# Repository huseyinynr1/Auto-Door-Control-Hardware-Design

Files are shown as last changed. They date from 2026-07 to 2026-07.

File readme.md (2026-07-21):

# Otomatik Tavuk Kümesi Kapısı Donanım Tasarımı

Bu sunum, **STM32F103C8T6 tabanlı otomatik tavuk kümesi kapısı kontrol sistemi** için hazırlanmış donanım tasarım dosyalarını içerir.

Sistem; Li-ion pil paketi ile beslenen ana kontrol kartı ve fırçalı DC motoru süren motor kontrol kartından oluşur. Ana kontrol kartı; kapı konumunu limit switch ile takip eder, IR sensör ile varlık algılar, pil gerilimini ADC üzerinden izler, TFT ekran, panel LED'leri ve panel butonları üzerinden kullanıcı arayüzünü yönetir. Motor kontrol kartı ise ana karttan gelen PWM/yön kontrol sinyalleriyle 12 V DC motoru sürer ve motor akım/gerilim geri bildirimlerini ana karta gönderir.

> Bu sunum ağırlıklı olarak PCB donanım tasarım dosyalarını içerir. Firmware/yazılım geliştirmesi buraya dahil değildir.

---

## Proje Özeti

Sistem ana beslemesini **Li-ion pil paketinden** alır. Ana kart üzerinde gerekli gerilim seviyelerini üretmek için güç dönüştürücü devreler bulunur. Motor sürüş işlemi ise ayrı tasarlanan **Automatic Door Motor Control Board** üzerinden gerçekleştirilir.

Sistemde bulunan temel donanımlar:

- **Li-ion pil paketi ana besleme girişi**
- **12 V → 5 V buck converter güç katı**
- **5 V → 3.3 V LDO regülatör güç katı**
- **STM32F103C8T6 mikrodenetleyici**
- **Harici 8 MHz HSE kristal**
- **Harici 32.768 kHz LSE kristal**
- **TFT ekran arayüzü**
- **Motor PWM ve yön kontrol çıkışları**
- **12 V DC worm gear motor sürüş katı**
- **Motor akım geri bildirimi**
- **Motor gerilim geri bildirimi**
- **Kullanıcı buton girişleri**
- **Panel durum LED çıkışları**
- **Düşük pil algılama devresi**
- **IR varlık/engel sensörü girişi**
- **Kapı tam açık / tam kapalı limit switch girişleri**
- **SWD programlama ve debug bağlantısı**
- **Ana besleme hatları için test point'ler**

Genel sistem bağlantısı:

```text
Main Board → PWM / Control Signals → Motor Control Board → DC Motor
                         ↑
              Motor Voltage / Current Feedback
```

---

## Donanım Blokları

### Güç Devresi

Kartın ana beslemesi Li-ion pil paketidir. Giriş gerilimi önce buck converter ile 5 V seviyesine düşürülür. Ardından 5 V hattından LDO regülatör ile 3.3 V lojik besleme hattı üretilir.

| Hat | Kaynak | Kullanım Amacı |
|---|---|---|
| Pil Girişi | Li-ion pil paketi | Ana sistem beslemesi |
| 5 V | Buck converter | Sensör/periferik beslemesi |
| 3.3 V | LDO regülatör | MCU ve lojik devre beslemesi |

Güç bölümünde giriş filtreleme, koruma elemanları, regüle çıkış devreleri ve pil gerilimi ölçüm katı bulunmaktadır.

Pil gerilimi, **50 kΩ / 10 kΩ** gerilim bölücü ile yaklaşık **1/6 oranında** küçültülür. Böylece nominal **12.6 V** pil gerilimi ADC ölçüm hattında yaklaşık **2.1 V**, ölçüm üst sınırı olarak değerlendirilen **18 V** ise yaklaşık **3.0 V** seviyesine dönüştürülür.

Gerilim bölücü çıkışı, **1 kΩ + 47 nF** alçak geçiren filtreden geçirilir ve **MCP6001** op-amp gerilim takipçisi ile tamponlanır. Op-amp, yüksek empedanslı gerilim bölücü düğümünü MCU ADC girişinden ayırarak `BATTERY_VOLTAGE` hattına düşük empedanslı ve daha kararlı bir ölçüm sinyali verir. Op-amp çıkışındaki **10 Ω** seri direnç, ADC hattındaki küçük kapasitif yükten op-amp çıkışını ayırır.

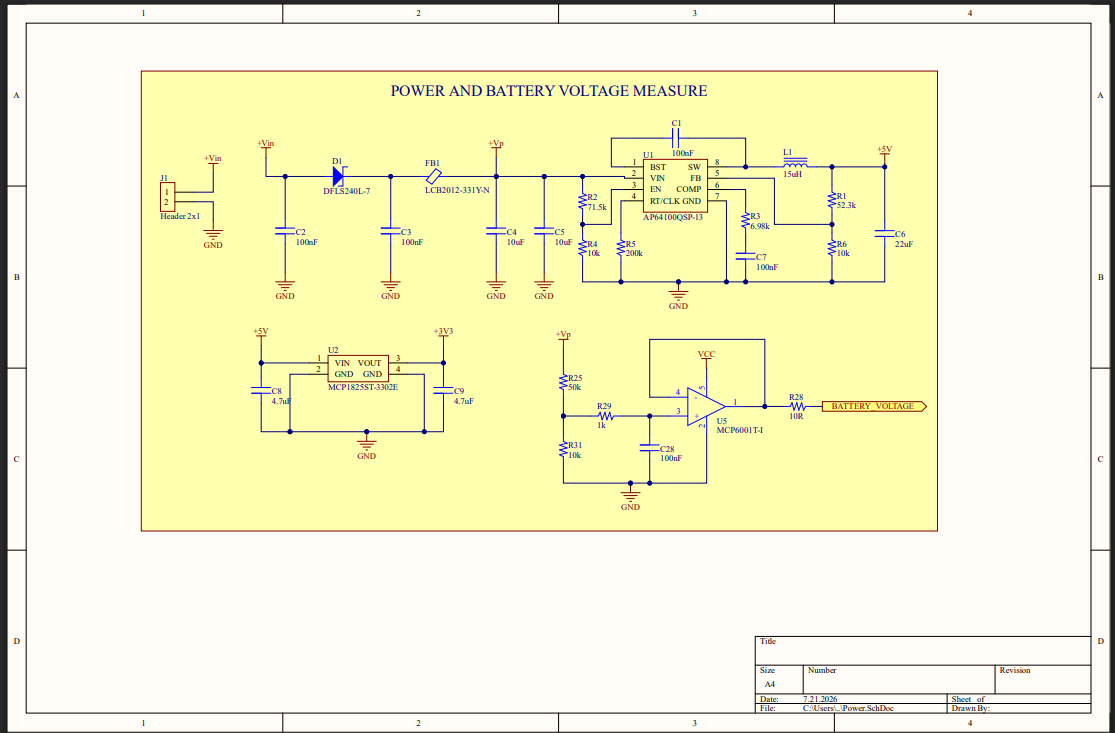
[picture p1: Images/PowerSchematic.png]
Power Schematic


---

### Mikrodenetleyici Bölümü

Ana kontrolcü olarak **STM32F103C8T6** kullanılmıştır.

MCU bölümünde bulunan temel yapılar:

- STM32F103C8T6 mikrodenetleyici
- Harici 8 MHz HSE kristal
- Harici 32.768 kHz LSE kristal
- MCU besleme dekuplaj kapasitörleri
- Reset / boot bağlantıları
- SWD programlama ve debug header'ı
- 3.3 V lojik besleme bağlantıları
- Pil gerilimi için `BATTERY_VOLTAGE` ADC girişi
- Motor akımı için `MOTOR_CURRENT` ADC girişi
- Motor uç gerilimleri için `MOTOR_VSENSE_A` ve `MOTOR_VSENSE_B` ADC girişleri

Motor kontrol kartından gelen op-amp tamponlu analog sinyaller, ana kart üzerinde MCU ADC kanallarına bağlanır. Her ADC girişinde, örnekleme anındaki kısa süreli akım ihtiyacını karşılamak ve yüksek frekanslı parazitleri azaltmak için MCU pinine yakın **4.7 nF** kondansatör kullanılır. Aynı yöntem `BATTERY_VOLTAGE` ölçüm girişinde de uygulanır.

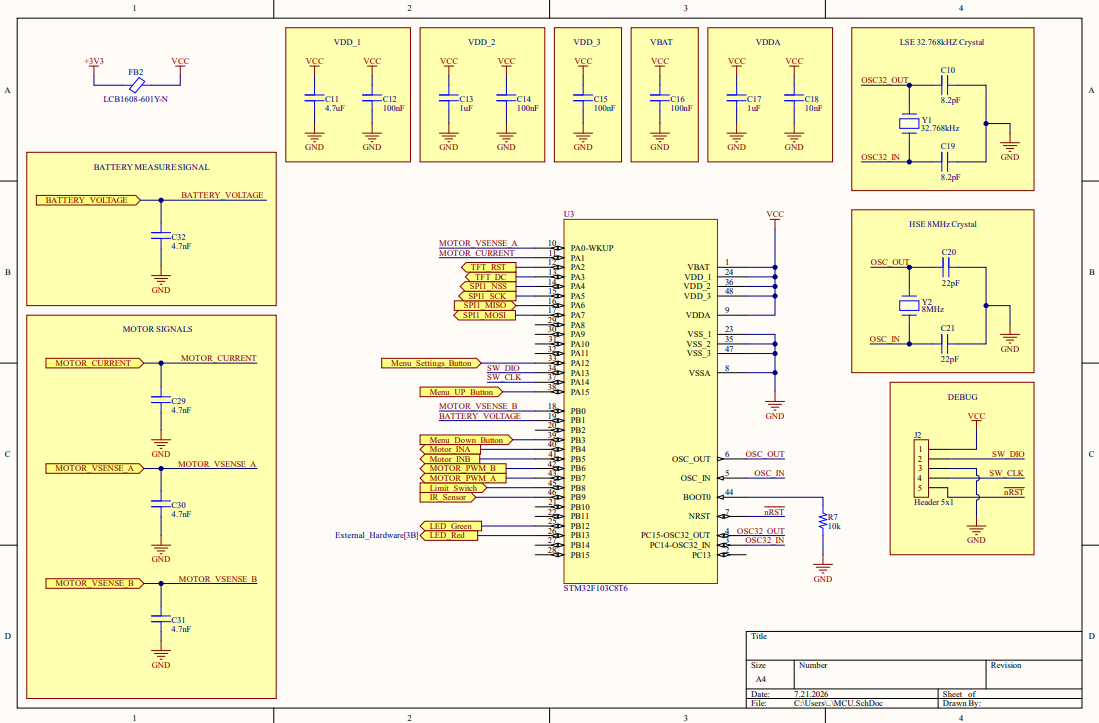
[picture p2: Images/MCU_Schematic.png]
MCU Schematic


---

### Harici Donanım Arayüzleri

Ana kontrol kartı, otomatik kapı sisteminde kullanılan harici donanımlar için gerekli bağlantı ve kontrol arayüzlerini içerir.

Desteklenen harici bağlantılar:

- TFT ekran bağlantısı
- Motor kontrol kartına PWM ve yön sinyalleri
- Motor akım/gerilim geri bildirim girişleri
- Kullanıcı buton girişleri
- Panel durum LED çıkışları
- IR varlık/engel sensörü girişi
- Kapı tam açık/tam kapalı limit switch girişi

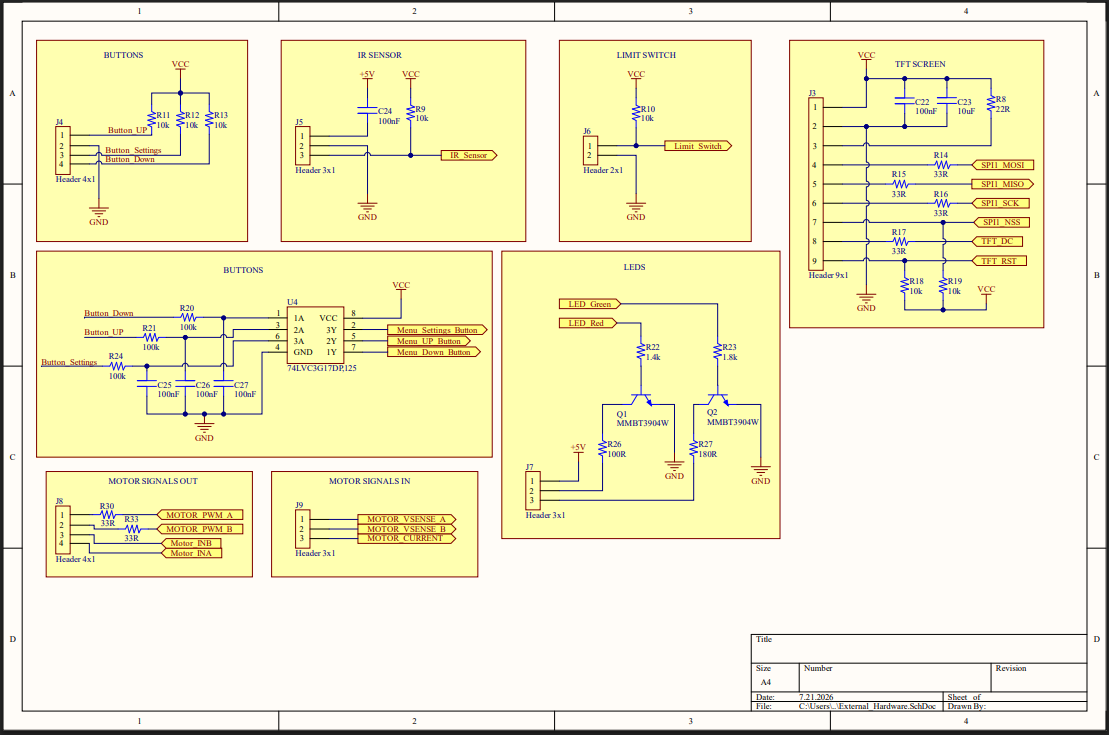
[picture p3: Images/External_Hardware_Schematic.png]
External Hardware Schematic


---

### Motor Control Board 

Motor Control Board, 12 V fırçalı DC motorun çift yönlü ve PWM kontrollü sürülmesi için ana kontrol kartından ayrı bir güç kartı olarak tasarlanmıştır. Kart yaklaşık **60 mm x 53 mm** boyutundadır ve dört adet montaj deliğine sahiptir.

Kartın temel bölümleri:

- Girişte resetlenebilir PTC sigorta, seri Schottky diyot ve SMBJ15CA TVS koruması
- 330 uF bulk kapasitör ile giriş filtreleme
- İki adet IR2103 yarım-köprü gate driver
- İki adet PJL9850 çift N-kanal MOSFET ile oluşturulan tam H-köprü
- Motorun çift yönlü sürülmesi ve PWM ile hız kontrolü
- 5 mOhm şönt direnç ve MCP6001 op-amp ile motor akım ölçümü
- Motorun iki terminali için gerilim bölücü, RC filtre ve MCP6001 buffer devreleri
- Ölçüm devreleri için filtrelenmiş 3.3 V analog besleme
- Ana kontrol kartına üç analog geri bildirim çıkışı

#### Motor Kontrol Sinyalleri

| Sinyal | Açıklama |
| --- | --- |
| `Motor_PWM_A` | A yarım-köprüsü PWM kontrolü |
| `Motor_PWM_B` | B yarım-köprüsü PWM kontrolü |
| `Motor_INA` | A yarım-köprüsü yön/alt anahtar kontrolü |
| `Motor_INB` | B yarım-köprüsü yön/alt anahtar kontrolü |

#### Ölçüm ve Geri Bildirim Sinyalleri

| Sinyal | Açıklama |
| --- | --- |
| `MOTOR_CURRENT` | Şönt direnç üzerinden yükseltilmiş motor akım ölçümü |
| `MOTOR_VREF_A` | Motorun A terminaline ait ölçeklendirilmiş gerilim |
| `MOTOR_VREF_B` | Motorun B terminaline ait ölçeklendirilmiş gerilim |

Bu geri bildirimler, yazılım tarafında motor akımının izlenmesi, sıkışma/stall durumunun belirlenmesi ve motor uç gerilimlerinden hareket bilgisinin değerlendirilmesi için kullanılacaktır.

#### Motor Güç ve Sürücü Şematiği

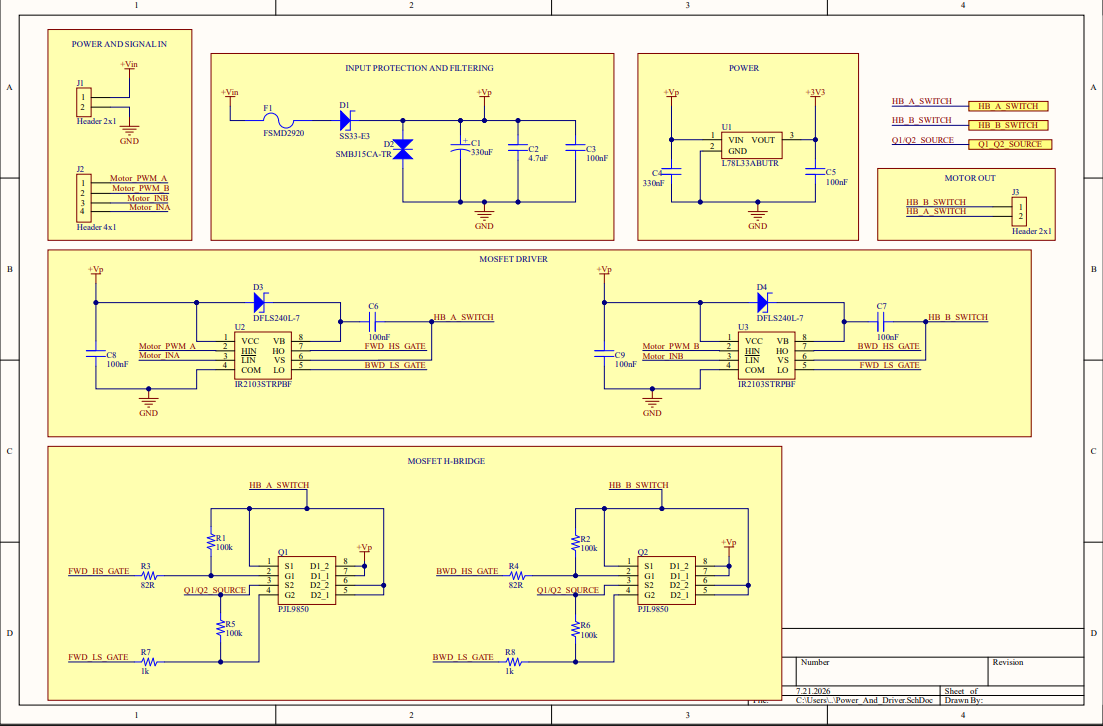
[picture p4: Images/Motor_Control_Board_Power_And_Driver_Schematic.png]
Motor Control Board V2 Power and Driver Schematic


#### Motor Ölçüm Şematiği

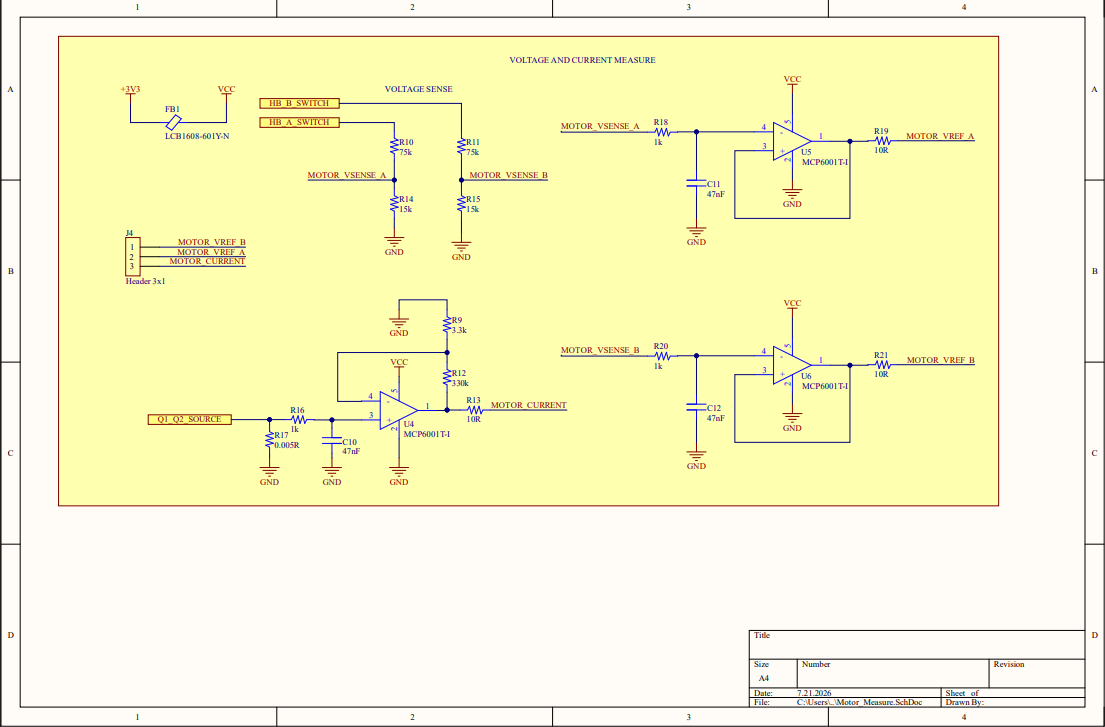
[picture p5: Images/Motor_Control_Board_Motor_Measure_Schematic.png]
Motor Control Board V2 Motor Measure Schematic


---

### Motor Driver Topology

Motor sürüş katı, **4 adet N-channel MOSFET** ile oluşturulmuş high-side / low-side **H-bridge** yapısına sahiptir. MOSFET'ler iki adet half-bridge MOSFET driver ile sürülür.

Kullanılan temel sürüş mantığı:

| Çalışma Durumu | PWM_A | IN_A | PWM_B | IN_B |
|---|---|---|---|---|
| Forward | Active | Active | Passive | Passive |
| Reverse | Passive | Passive | Active | Active |
| Stop | Passive | Passive | Passive | Passive |

Bu yapı sayesinde motor yön kontrolü ve PWM tabanlı hız/enerji kontrolü ana kart üzerinden gerçekleştirilebilir.

### Input Protection and Filtering

Motor kontrol kartının giriş bölümünde güç hattını korumak ve filtrelemek için aşağıdaki yapılar bulunur:

- PTC resettable fuse
- Reverse polarity protection Schottky diode
- TVS diode
- Bulk input capacitor
- MLCC input filter capacitors

Bu bölüm, motor kartının giriş beslemesini ters bağlantı, ani gerilim darbeleri ve besleme hattı gürültülerine karşı daha dayanıklı hale getirmek için tasarlanmıştır.

### Motor Current Sensing

Motor akımı low-side shunt direnç üzerinden ölçülür. Shunt üzerinde oluşan düşük seviyeli voltaj, op-amp tabanlı sinyal koşullandırma devresiyle ana karta uygun ölçüm sinyali haline getirilir.

Bu geri bildirim aşağıdaki amaçlarla kullanılabilir:

- Motor yük durumunun izlenmesi
- Sıkışma / stall durumunun algılanması
- Aşırı akım durumlarının yazılımsal olarak takip edilmesi
- Motor hareketinin güvenlik açısından denetlenmesi

### Motor Voltage Sensing

Motorun her iki terminali (`HB_A_SWITCH` ve `HB_B_SWITCH`) ayrı ayrı ölçülmektedir. Terminal gerilimleri, 75 kΩ / 15 kΩ gerilim bölücüler ile yaklaşık **1/6 oranında düşürülerek** `MOTOR_VSENSE_A` ve `MOTOR_VSENSE_B` sinyallerine dönüştürülür.

Bu sinyaller, 1 kΩ direnç ve 47 nF kondansatörden oluşan giriş filtresinden geçirildikten sonra MCP6001 op-amp'ları tarafından gerilim takipçisi (unity-gain buffer) olarak tamponlanır. Böylece gerilim bölücü devresi ADC girişinden izole edilir ve ana karta daha kararlı, düşük empedanslı ölçüm sinyalleri iletilir.

Motor gerilim geri bildirim sinyalleri:

- `MOTOR_VREF_A`
- `MOTOR_VREF_B`

Ana kart, bu iki geri bildirim sinyali arasındaki farkı kullanarak motor uçları arasındaki gerçek gerilimi hesaplayabilir.

Motor akım geri bildirim sinyali:

- `MOTOR_CURRENT`

### Main Board Interface

Motor kontrol kartı ana karta aşağıdaki sinyaller üzerinden bağlanır:

| Sinyal | Yön | Açıklama |
|---|---|---|
| `Motor_PWM_A` | Main Board → Motor Control Board | A yönü PWM kontrol sinyali |
| `Motor_INA` | Main Board → Motor Control Board | A yönü enable/direction kontrol sinyali |
| `Motor_PWM_B` | Main Board → Motor Control Board | B yönü PWM kontrol sinyali |
| `Motor_INB` | Main Board → Motor Control Board | B yönü enable/direction kontrol sinyali |
| `MOTOR_VREF_A` | Motor Control Board → Main Board | Motor A terminali gerilim geri bildirimi |
| `MOTOR_VREF_B` | Motor Control Board → Main Board | Motor B terminali gerilim geri bildirimi |
| `MOTOR_CURRENT` | Motor Control Board → Main Board | Motor akım geri bildirimi |

### PCB Design

Motor kontrol kartı **2-layer PCB** olarak tasarlanmıştır. Kart üzerinde motor akımı taşıyan güç yolları geniş tutulmuş, GND dönüş yolu için polygon pour yapısı kullanılmıştır. Motor akımı, motor gerilimi ve sürücü kontrol sinyalleri ayrı izleme/geri bildirim hatları olarak ana karta taşınır.

---

## PCB Görünümleri

### Main Board - PCB Üst Görünüm

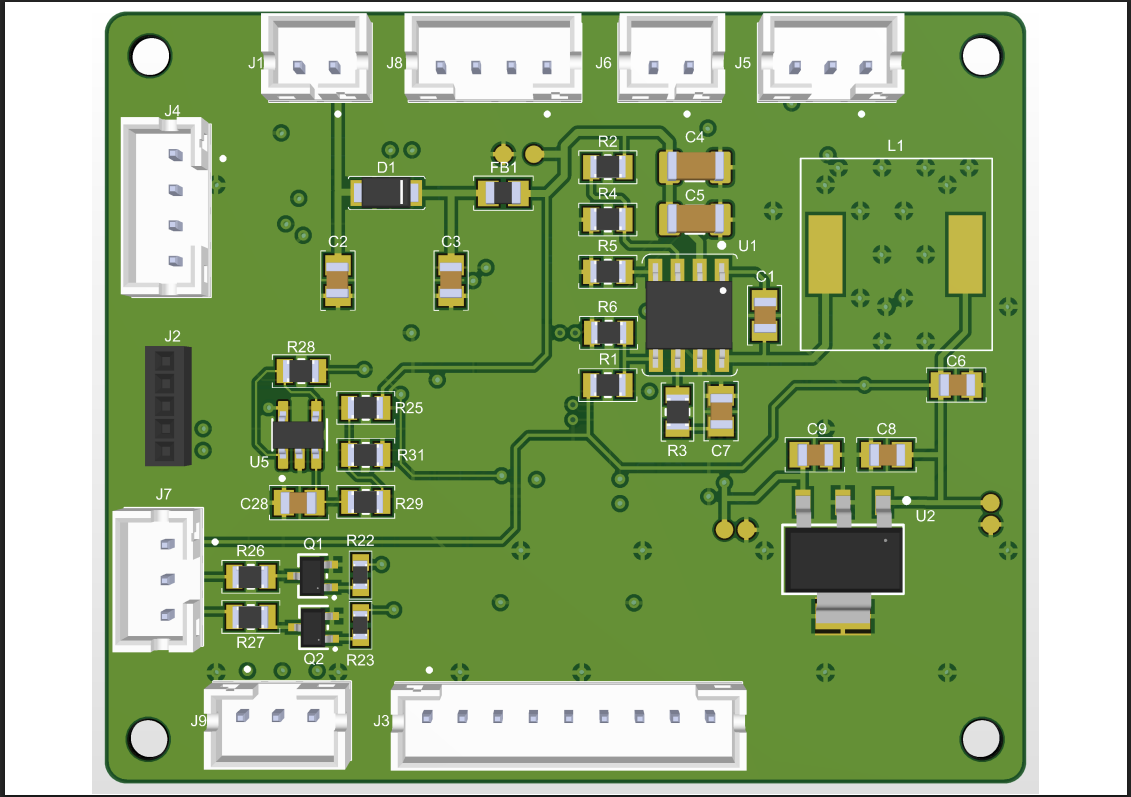
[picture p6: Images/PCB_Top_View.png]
Main Board PCB Top View


### Main Board - PCB Alt Görünüm

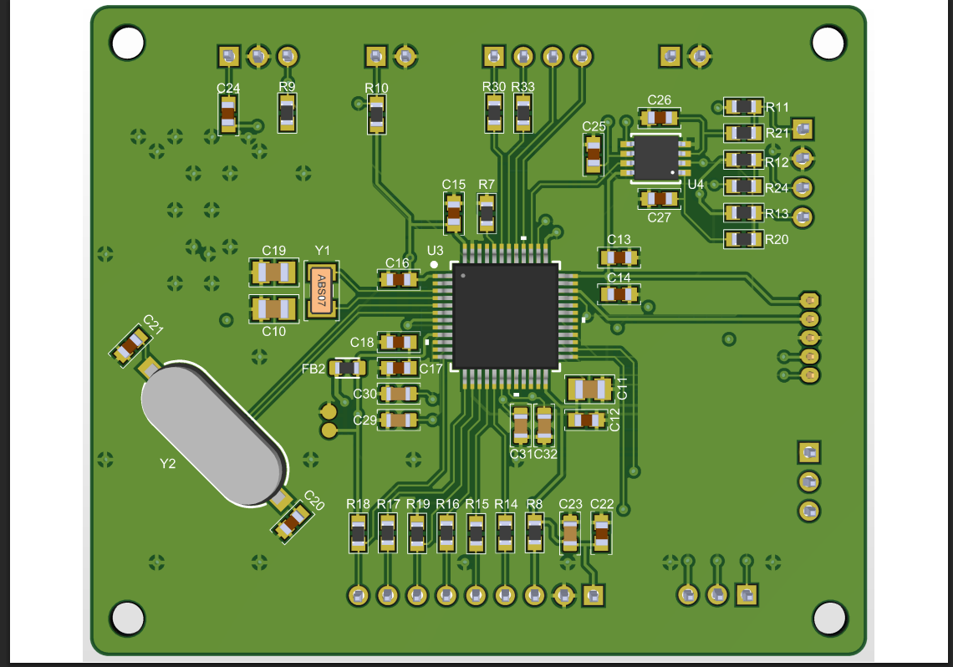
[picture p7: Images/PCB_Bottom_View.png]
Main Board PCB Bottom View


### Motor Control Board - PCB Üst Görünüm

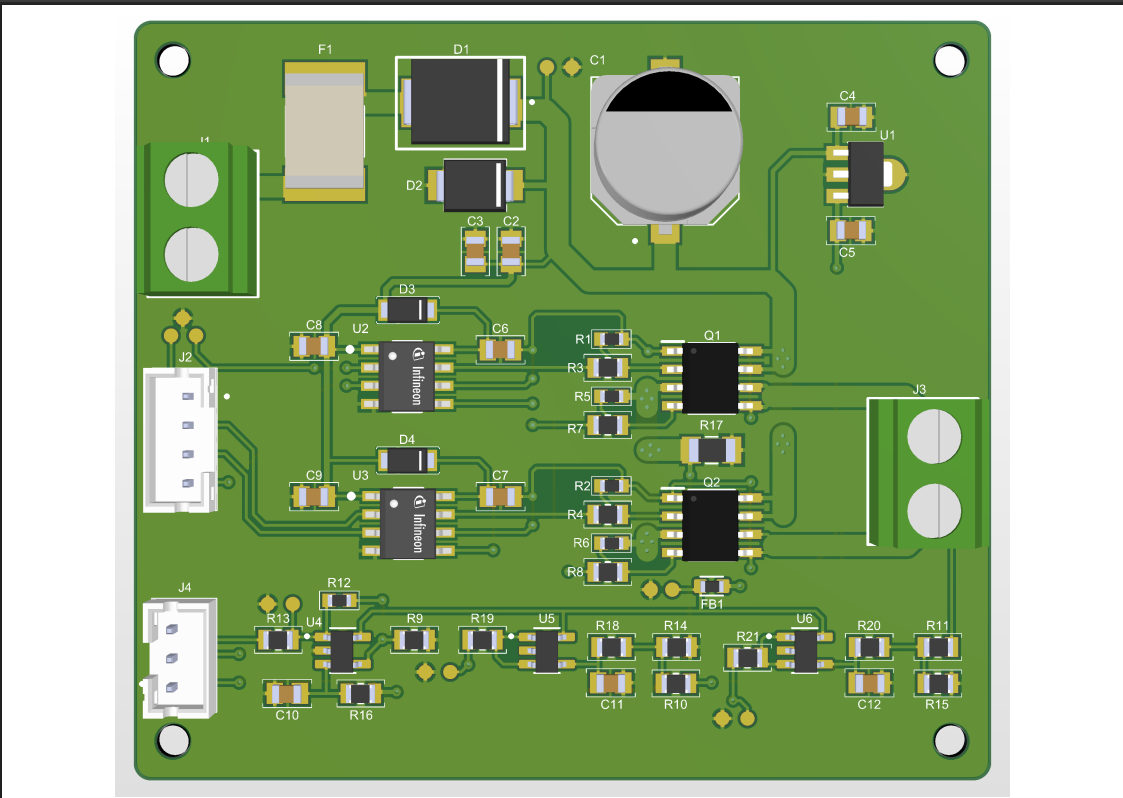
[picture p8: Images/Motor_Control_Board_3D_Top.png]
Motor Control Board 3D Top View


---

## Dosya Yapısı

```text
.
├── Design_Files/
│   ├── Chicken_Coop_Door_Main_Board_V3.PcbDoc
│   ├── Chicken_Coop_Door_Main_Board_V3.PrjPcb
│   ├── Chicken_Coop_Door_Main_Board_V3.PrjPcbStructure
│   ├── Power.SchDoc
│   ├── MCU.SchDoc
│   ├── External_Hardware.SchDoc
│   ├── Chicken_Coop_Door_Motor_Control_Board_V2.PrjPcb
│   ├── Chicken_Coop_Door_Motor_Control_Board_V2.PrjPcbStructure
│   ├── Chicken_Coop_Door_Motor_Control_Board_V2.PcbDoc
│   └── Power_And_Driver.SchDoc
│   └── Motor_Measure.SchDoc
│
├── Images/
│   ├── Power.png
│   ├── MCU_Schematic.png
│   ├── External_Hardware_Schematic.png
│   ├── Motor_Control_Board_Power_And_Driver_Schematic.png
│   ├── Motor_Control_Board_Motor_Measure_Schematic.png
│   ├── PCB_Top_View.png
│   ├── PCB_Bottom_View.png
│   ├── Motor_Control_Board_3D_Top.png
│
├── Production/
│   ├── Bill of Materials-Chicken_Coop_Door_Main_Board_V3.xlsx
│   └── Bill of Materials-Chicken_Coop_Door_Motor_Control_Board_V2.xlsx
│
└── README.md
```

---

## Tasarım Dosyaları

PCB tasarımları **Altium Designer** kullanılarak hazırlanmıştır.

Sunumda bulunan temel Altium dosyaları:

| Dosya | Açıklama |
|---|---|
| `Chicken_Coop_Door_Main_Board_V3.PrjPcb` | Ana kontrol kartı Altium PCB proje dosyası |
| `Chicken_Coop_Door_Main_Board_V3.PcbDoc` | Ana kontrol kartı PCB layout dosyası |
| `Power.SchDoc` | Ana kontrol kartı güç devresi şematik dosyası |
| `MCU.SchDoc` | Mikrodenetleyici devresi şematik dosyası |
| `External_Hardware.SchDoc` | Harici donanım arayüzleri şematik dosyası |
| `Chicken_Coop_Door_Main_Board_V3.PrjPcbStructure` | Ana kontrol kartı Altium proje yapı dosyası |
| `Chicken_Coop_Door_Motor_Control_Board_V2.PrjPcb` | Motor kontrol kartı Altium PCB proje dosyası |
| `Chicken_Coop_Door_Motor_Control_Board_V2.PcbDoc` | Motor kontrol kartı PCB layout dosyası |
| `Power_And_Driver.SchDoc` | Motor kontrol kartı şematik dosyası |
| `Motor_Measure.SchDoc` | Motor kontrol kartı şematik dosyası |

---

## Malzeme Listesi

BOM dosyaları `Production` klasörü altında yer almaktadır:

```text
Production/Bill of Materials-Chicken_Coop_Door_Main_Board_V3.xlsx
Production/Bill of Materials-Chicken_Coop_Door_Motor_Control_Board_v2.xlsx
```

Bu dosyalar, projede kullanılan komponentleri, değerleri, üretici bilgilerini ve footprint bilgilerini içerir.

---

## Ana Fonksiyonel Bölümler

### 1. Pil Girişi ve Güç Regülasyonu

Kartın ana beslemesi, seri bağlı Li-ion hücrelerden oluşan pil paketi üzerinden sağlanacak şekilde tasarlanmıştır. Pil gerilimi buck converter devresi ile 5 V seviyesine düşürülür. Ardından 5 V hattından LDO regülatör ile 3.3 V lojik besleme hattı elde edilir.

Pil gerilimi ayrıca 50 kΩ / 10 kΩ bölücü, 1 kΩ + 47 nF alçak geçiren filtre ve MCP6001 buffer üzerinden `BATTERY_VOLTAGE` sinyaline dönüştürülerek MCU ADC kanalına iletilir. Böylece pil seviyesi ve düşük/aşırı gerilim durumları ayrı comparator devresi yerine yazılım tarafından izlenebilir.

### 2. MCU Kontrol Bölümü

STM32F103C8T6 mikrodenetleyici aşağıdaki işlemleri yönetmek için kullanılır:

- Kapı motor kontrol komutlarının üretilmesi
- Kullanıcı butonlarının okunması
- TFT ekran arayüzü
- Sensör ve limit switch girişlerinin okunması
- `BATTERY_VOLTAGE` ADC ölçümünden pil durumunun takip edilmesi
- Kırmızı ve yeşil panel LED çıkışlarının kontrol edilmesi
- `MOTOR_CURRENT`, `MOTOR_VSENSE_A` ve `MOTOR_VSENSE_B` ADC geri bildirimlerinin değerlendirilmesi

### 3. Motor Kontrol Arayüzü

Ana kontrol kartı motor güç katını doğrudan üzerinde taşımaz. Bunun yerine **Automatic Door Motor Control Board** kartına PWM ve yön kontrol sinyalleri gönderir. Motor kontrol kartı bu sinyallerle H-bridge güç katını sürer ve motoru ileri/geri yönde çalıştırır.

### 4. Motor Sürüş ve Geri Bildirim Bölümü

Motor kontrol kartı üzerinde 12 V DC motoru süren H-bridge güç katı, MOSFET driver devreleri, giriş koruma/filtreleme yapısı, motor akım ölçüm devresi ve motor gerilim ölçüm devreleri bulunur.

Bu yapı sayesinde motor sürüşü ana karttan fiziksel olarak ayrılır ve motorun elektriksel davranışı geri bildirim sinyalleri ile izlenebilir.

### 5. Kullanıcı Arayüzü

Kullanıcı arayüzü için ana kart üzerinde aşağıdaki bağlantılar yer alır:

- TFT ekran bağlantısı
- Kullanıcı butonları
- Panel durum LED çıkışları

Bu arayüzler, sistem durumunun görüntülenmesi ve kullanıcıdan manuel komut alınması için kullanılır.

### 6. Sensör ve Geri Bildirim Girişleri

Kart üzerinde kapı hareketini ve çevresel koşulları takip etmek için çeşitli girişler bulunur:

- IR varlık sensörü
- Kapı tam açık - kapalı limit switch'i
- Düşük pil algılama girişi
- Motor akım geri bildirimi
- Motor gerilim geri bildirimi

Bu sinyaller, kapı hareketinin güvenli ve kontrollü şekilde yönetilmesini sağlar.

---

## Yazar

**Hüseyin Yanar**

Elektrik-Elektronik Mühendisi

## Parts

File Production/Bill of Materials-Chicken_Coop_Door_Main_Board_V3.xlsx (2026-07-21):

Comment | Description | Designator | Footprint | LibRef | Quantity | Capacitance | Resistance | Manufacturer | Manufacturer Code | Manufacturer Product Number | Manufacturer_Part_Number | Manufacturer_Name
100nF | MLCC 0805 100nF 50VDC ±10% X7R, MLCC (2012) 0805 10nF 50VDC ±10% X7R | C1, C2, C3, C7, C28 | CAPC2012X145N 0805 | CAP 0805 100nF, CAP 0805 100nF CC0805JRX7R9BB104, CAP 0805 10nF CC0805KRX7R9BB103 | 5 | 100nF, 10nF |  | SAMSUNG, YAGEO | CL21B104KBCNNNC, CC0805JRX7R9BB104, CC0805KRX7R9BB103
10uF | MLCC (3216) 1206 10uF 50VDC ±10% X5R | C4, C5 | CAPC 1206 3216X180N | CAP 1206 10uF CL31A106KBHNNNE | 2 | 10 uF |  | Samsung Electro-Mechanics |  | CL31B225KCHSNNE
22uF | MLCC (2012) 0805 22uF 16VDC ±10% X5R CL21A226KOQNNNE | C6 | CAPC2012X145N 0805 | CAP 0805 22uF CL21A226KOQNNNE | 1 | 22 µF |  | SAMSUNG |  | CL21A226KOQNNNE
4.7uF | MLCC (2012) 0805 4.7uF 25VDC ±10% X5R, MLCC (2012) 0805 4.7uF 16VDC ±10% X7R AUTOMOTIVE | C8, C9, C11 | CAPC2012X145N 0805 | CAP 0805 4.7uF CL21A475KAQNNNE, CAP 0805 4.7uF CL21B475KOQVPNE | 3 | 4.7uF |  | SAMSUNG |  | CL21A475KAQNNNE, CL21B475KOQVPNE
8.2pF | MLCC (2012) 0805 8.2pF 50VDC ±0.5pF C0G (NP0) | C10, C19 | CAPC2012X145N 0805 | CAP 0805 8.2pF CC0805DRNPO9BN8R2 | 2 | 8.2pF |  | YAGEO | CC0805DRNPO9BN8R2
100nF | MLCC (1608) 0603 100nF 25VDC ±10% X7R | C12, C14, C15, C16, C22, C24, C25, C26, C27 | CAPC 0603 1608X90N | CAP 0603 100nF CC0603KPX7R8BB104 | 9 | 100nF |  | YAGEO |  | CC0603KPX7R8BB104
1uF | MLCC (1608) 0603 1uF 16VDC ±10% X5R | C13, C17 | CAPC 0603 1608X90N | CAP 0603 1uF C0603C105K4PACTU | 2 | 1uF |  | KEMET |  | C0603C105K4PACTU
10nF | MLCC (1608) 0603 10nF 25VDC ±10% X7R | C18 | CAPC 0603 1608X90N | CAP 0603 10nF CL10B103KA8NNNC | 1 | 10nF |  | SAMSUNG |  | CL10B103KA8NNNC
22pF | MLCC (1608) 0603 22pF 50VDC ±5% C0G (NP0) | C20, C21 | CAPC 0603 1608X90N | CAP 0603 22pF CC0603JRNPO9BN220 | 2 | 22pF |  | YAGEO |  | CC0603JRNPO9BN220
10uF | MLCC (1608) 0603 10uF 10VDC ±10% X5R | C23 | CAPC1608X90N 0603 | CAP 0603 10uF CL10A106KP8NNNC | 1 | 10uF |  | SAMSUNG | CL10A106KP8NNNC
4.7nF | MLCC (1608) 0603 4.7nF 50VDC ±10% X7R | C29, C30, C31, C32 | CAPC1608X90N 0603 | CAP 0603 4.7nF CL10B472KB8NNNC | 4 | 4.7nF |  | SAMSUNG | CL10B472KB8NNNC
DFLS240L-7 | DIODE SCHOTTK 40V 2A POWERDI 123 | D1 | DIODE DFLS240L-7 POWERDI 123 | DIODE SCHOTTKY DFLS240L-7 | 1 |  |  | Diodes Incorporated |  | DFLS240L-7
LCB2012-331Y-N | FERRITE BEAD 0805 330R/100MHZ SMD | FB1 | BEADC2012X105N MPZ2012S601ATD25 | Ferrite Bead LCB2012-331Y-N | 1 |  |  | CORE MASTER |  | LCB2012-331Y-N
LCB1608-601Y-N | 600 Ohms @ 100 MHz 1 Power Line Ferrite Bead 0603 (1608 Metric) 1A 200mOhm | FB2 | MPZ1608S601ATA00 0603 1608X95N | Ferrite Bead LCB1608-601Y-N | 1 |  |  | CORE MASTER | LCB1608-601Y-N
Header 2x1 | CON.T.B.2.00MM 2P 180C MALE CONNFLY | J1, J6 | JST_B2B-PH-K-S 1x2 Header | Header 2x1 DS1066-2MVW6X | 2 |  |  | CONNFLY |  | DS1066-2MVW6X
Header 5x1 | FEMALE HEADER 5PIN(1x5) 2.54mm THT V/T BAG | J2 | Header 5x1 FEMALE Header | Header 5x1 Female Header | 1 |  |  | KLS ELECTRONIC |  | L-KLS1-208-1-05-S
Header 9x1 | CON.T.B.2.00MM 9P 180C MALE WHITE CONNFLY | J3 | Header 9x1 JST_B9B-PH-K-S | Header 9x1 DS1066-9MVW6S | 1 |  |  | CONNFLY |  | DS1066-9MVW6S
Header 4x1 | CON.T.B.2MM 4P 180C MALE WHITE CONNFLY | J4, J8 | JST_B4B-PH-K-S 1x4 Header | Header 4x1 DS1066-4MVW6X | 2 |  |  | CONNFLY |  | DS1066-4MVW6X
Header 3x1 | CON.T.B.2.00MM 3P 180C MALE CONNFLY | J5, J7, J9 | JST_B3B-PH-K-S 1x3 Header | Header 3x1 DS1066-3MVW6X | 3 |  |  | CONNFLY |  | DS1066-3MVW6X
15uH | INDUCTOR POWER 15UH 10X10X4.5MM SMD | L1 | Inductor SRI1004-150M | 15uH Inductor SRI1004-150M | 1 |  |  | CORE MASTER |  | SRI1004-150M
MMBT3904W | Bipolar (BJT) Transistor NPN 40 V 200 mA 150 mW Surface Mount SOT-323 | Q1, Q2 | MMBT3904_PNJ | NPN Transistor MMBT3904W | 2 |  |  | Panjit International Inc. |  | MMBT3904W_R1_00001
52.3k | RES.(2012) 0805 52.3K Ohms 1% 1/8W-S 100PPM | R1 | RES 0805 YAGEO C2012X60N | RES 0805 52.3k 0805S8F5232T5E | 1 |  | 52.3k Ohms | ROYALOHM | 0805S8F5232T5E
71.5k | RES.(2012) 0805 71.5k Ohms 1% 1/8W-S 100PPM | R2 | RES 0805 YAGEO C2012X60N | RES 0805 71.5k Ohms 0805S8F7152T5E | 1 |  | 71.5k Ohms | ROYALOHM | 0805S8F7152T5E
6.98k | RES.(2012) 0805 6.98K Ohms 1% 1/10W 100PPM | R3 | RES 0805 YAGEO C2012X60N | RES 0805 6.98k 0805WAF6981T5E | 1 |  | 6.98k Ohms | ROYALOHM | 0805WAF6981T5E
10k | RES.(2012) 0805 10K Ohms 1% 1/8W-S 100PPM | R4, R6, R31 | RES 0805 YAGEO C2012X60N | RES 0805 10k 0805S8F1002T5E | 3 |  | 10k Ohms | ROYALOHM | 0805S8F1002T5E
200k | RES.(2012) 0805 200K Ohms 1% 1/8W-S 100PPM | R5 | RES 0805 YAGEO C2012X60N | RES 0805 200k 0805S8F2003T5E | 1 |  | 200k Ohms | ROYALOHM | 0805S8F2003T5E
10k | RES.(1608) 0603 10K Ohms 5% 1/10W-S 100PPM | R7, R9, R10, R11, R12, R13, R18, R19 | RES 0603 ROYALOHM | RES 0603 10k 0603SAJ0103T5E | 8 |  | 10 kOhms | ROYALOHM |  | 0603SAJ0103T5E
22R | RES.(1608) 0603 22 Ohms 5% 1/10W-S 200PPM | R8 | RES 0603 ROYALOHM | RES 0603 22 Ohms 0603SAJ0220T5E | 1 |  | 22 Ohms | ROYALOHM |  | 0603SAJ0220T5E
33R | RES.(1608) 0603 33 Ohms 5% 1/10W-S 200PPM | R14, R15, R16, R17, R30, R33 | RES 0603 ROYALOHM | RES 0603 33 Ohms 0603SAJ0330T5E | 6 |  | 33 Ohms | ROYALOHM |  | 0603SAJ0330T5E
100k | RES.(1608) 0603 100K Ohms 1% 1/10W-S 100PPM | R20, R21, R24 | RES 0603 ROYALOHM | RES 0603 100k 0603SAF1003T5E | 3 |  | 100 kOhms | ROYALOHM |  | 0603SAF1003T5E
1.4k | RES.(1608) 0603 1.4K Ohms 1% 1/10W-S 100PPM | R22 | RES 0603 ROYALOHM | RES 0603 1.4k 0603SAF1401T5E | 1 |  | 1.4 k Ohms | ROYALOHM |  | 0603SAF1401T5E
1.8k | RES.(1608) 0603 1.8K Ohms 1% 1/10W-S 100PPM | R23 | RES 0603 ROYALOHM | RES 0603 1.8k 0603SAF1801T5E | 1 |  | 1.8k Ohms | ROYALOHM |  | 0603SAF1801T5E
50k | RES.(2012) 0805 50K Ohms 1% 1/8W-S 100PPM | R25 | RES 0805 YAGEO C2012X60N | RES 0805 50k 0805S8F5002T5E | 1 |  | 50 kOhms | ROYALOHM | 0805S8F5002T5E
100R | RES.(2012) 0805 100 Ohms 1% 1/8W-S 200PPM | R26 | RES 0805 YAGEO C2012X60N | RES 0805 100R 0805S8F1000T5E | 1 |  | 100 Ohms | ROYALOHM | 0805S8F1000T5E
180R | RES.(2012) 0805 180 Ohms 5% 1/8W-S 100PPM | R27 | RES 0805 YAGEO C2012X60N | RES 0805 180R 0805S8J0181T5E | 1 |  | 180 Ohms | ROYALOHM | 0805S8J0181T5E
10R | RES.(2012) 0805 10 Ohms 5% 1/8W-S 400PPM | R28 | RES 0805 YAGEO C2012X60N | RES 0805 10 Ohms 0805S8J0100T5E | 1 |  | 10 Ohms | ROYALOHM | 0805S8J0100T5E
1k | RES.(2012) 0805 1K Ohms 1% 1/8W-S 100PPM | R29 | RES 0805 YAGEO C2012X60N | RES 0805 1k Ohms 0805S8F1001TDE | 1 |  | 1k Ohms | ROYALOHM | 0805S8F1001TDE
AP64100QSP-13 | Buck Switching Regulator IC Positive Adjustable 0.8V 1 Output 1A 8-SOIC (0.154", 3.90mm Width) Exposed Pad | U1 | AP64100QSP-13 SOIC-8 Buck Converter | AP64100QSP-13 Buck converter | 1 |  |  | Diodes Incorporated |  | AP64100QSP-13
MCP1825ST-3302E | Linear Voltage Regulator IC Positive Fixed 1 Output 500mA SOT-223-3 | U2 | LDO MCP1825ST-3302E/DB SOT-223_3MC_MCH | LDO 3V3 MCP1825ST-3302E/DB | 1 |  |  | Microchip Technology |  | MCP1825ST-3302E/DB
STM32F103C8T6 | Mainstream Performance line, Arm Cortex-M3 MCU with 64 Kbytes of Flash memory, 72 MHz CPU, motor control, USB and CAN | U3 | LQFP48_STM | STM32F103C8T6 | 1 |  |  |  |  |  | STM32F103C8T6 | STMicroelectronics
74LVC3G17DP,125 | Buffer, Non-Inverting 3 Element 1 Bit per Element Push-Pull Output 8-TSSOP | U4 | Schmitt Triger 74LVC3G17DP,125 TSSOP8_SOT505-2_NEX | Schmitt Triger 74LVC3G17DP,125 | 1 |  |  | Nexperia USA Inc. |  | 74LVC3G17DP,125
MCP6001T-I | Standard (General Purpose) Amplifier 1 Circuit Rail-to-Rail SOT-23-5 | U5 | MCP6001T-I/OT OPAMP SOT-23-5 | MCP6001T-I/OT OP-AMP 1 CH LOW POWER | 1 |  |  | Microchip Technology |  | MCP6001T-I/OT
32.768kHz | CRYSTAL 32.768kHz 6pF SMD | Y1 | XTAL_ABS07-120-32.768KHZ-T | CRYSTAL 32.768kHz ABS07-120-32.768KHZ-T | 1 |  |  | Abracon LLC |  | ABS07-120-32.768KHZ-T
8MHz | CRYSTAL 8MHz HC49SMT 16pF SMD TR RALTRON | Y2 | XTAL_J49SMH-A-G-G-K-8M0_JAU | CRYSTAL 8MHz AS-8.000-16-SMD-TR | 1 |  |  | RALTRON | AS-8.000-16-SMD-TR

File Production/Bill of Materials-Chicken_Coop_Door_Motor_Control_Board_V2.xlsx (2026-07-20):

Comment | Description | Designator | Footprint | LibRef | Quantity | Manufacturer Code | Manufacturer | Manufacturer Product Number | Resistance | Capacitance | Package / Case | Package Size
330uF | 330 µF 35 V Aluminum Electrolytic Capacitors Radial, Can - SMD 2000 Hrs @ 105°C | C1 | CAP_EEEFK1V331P | CAP Electrolytic EEE-FK1V331P | 1 |  | Panasonic Industry | EEE-FK1V331P |  | 330uF | Radial, Can - SMD
4.7uF | MLCC (2012) 0805 4.7uF 16VDC ±10% X7R AUTOMOTIVE | C2 | CAPC2012X145N 0805 | CAP 0805 4.7uF CL21B475KOQVPNE | 1 |  | SAMSUNG | CL21B475KOQVPNE |  | 4.7uF |  | 0805
100nF | MLCC 0805 100nF 50VDC ±10% X7R | C3, C5, C6, C7, C8, C9 | CAPC2012X145N 0805 | CAP 0805 100nF CC0805JRX7R9BB104 | 6 | CC0805JRX7R9BB104 | YAGEO |  |  | 100nF |  | 0805
330nF | MLCC (2012) 0805 330nF 50VDC ±10% X7R | C4 | CAPC2012X145N 0805 | CAP 0805 330nF CL21B334KBFNNNE | 1 |  | SAMSUNG | CL21B334KBFNNNE |  | 330nF |  | 0805
47nF | CL21B473KBCNNNC | C10, C11, C12 | CAPC2012X145N 0805 | CAP 0805 47nF CL21B473KBCNNNC | 3 |  | SAMSUNG | CL21B473KBCNNNC |  | 47nF |  | 0805
SS33-E3 | DIODE SCHOTTKY 30V 3A DO214AB | D1 | SS33-E3/57T Schottky Diode | DIODE SCHOTTKY SS33-E3/57T | 1 |  | Vishay General Semiconductor - Diodes Division | SS33-E3/57T |  |  | DO-214AB, SMC
SMBJ15CA-TR | 24.4V Clamp 25.1A Ipp Tvs Diode Surface Mount SMB | D2 | TVS DIODE SMBJ15CA-TR | TVS DIODE SMBJ15CA-TR | 1 |  | STMicroelectronics | SMBJ15CA-TR |  |  | DO-214AA, SMB
DFLS240L-7 | DIODE SCHOTTK 40V 2A POWERDI 123 | D3, D4 | DIODE DFLS240L-7 POWERDI 123 | DIODE SCHOTTKY DFLS240L-7 | 2 |  | Diodes Incorporated | DFLS240L-7 |  |  | POWERDI®123
FSMD2920 | PTC Resettable Fuse 24V 2 A Ih Surface Mount 2920 (7351 Metric), Concave | F1 | FUSE FSMD200-24-2920-R | FUSE FSMD200-24-2920-R | 1 |  | RFE/Fuzetec | FSMD200-24-2920-R |  |  | 2920 (7351 Metric)
LCB1608-601Y-N | 600 Ohms @ 100 MHz 1 Power Line Ferrite Bead 0603 (1608 Metric) 1A 200mOhm | FB1 | MPZ1608S601ATA00 0603 1608X95N | Ferrite Bead LCB1608-601Y-N | 1 | LCB1608-601Y-N | CORE MASTER |  |  |  |  | 0603
Header 2x1 | TERM.BLK.5.00MM 2P PCB TYPE GREEN | J1, J3 | 2x1 Terminal Block | Terminal Block 2x1 | 2 |  | DEGSON | DG130-5.0-02P-14-00AH
Header 4x1 | CON.T.B.2MM 4P 180C MALE WHITE CONNFLY | J2 | JST_B4B-PH-K-S 1x4 Header | Header 4x1 DS1066-4MVW6X | 1 |  | CONNFLY | DS1066-4MVW6X
Header 3x1 | CON.T.B.2.00MM 3P 180C MALE CONNFLY | J4 | JST_B3B-PH-K-S 1x3 Header | Header 3x1 DS1066-3MVW6X | 1 |  | CONNFLY | DS1066-3MVW6X
PJL9850 | Low Voltage MOSFET (20-40V,Rds(on)<1) - PJL9850 , N/N Channel, Dual, 5.4A, 40V, SOP-8 | Q1, Q2 | PJL850 N-CH MOSFET | PJL9850 N-Ch MOSFET | 2 |  | PANJIT | PJL9850_R2_00001 |  |  | SOP8
100k | RES.(1608) 0603 100K Ohms 1% 1/10W-S 100PPM | R1, R2, R5, R6 | RES 0603 ROYALOHM | RES 0603 100k 0603SAF1003T5E | 4 |  | ROYALOHM | 0603SAF1003T5E | 100 kOhms |  | 0603 (1608 Metric)
82R | RES.(2012) 0805 82 Ohms 5% 1/8W-S 200PPM | R3, R4 | RES 0805 YAGEO C2012X60N | RES 0805 82 Ohms 0805S8J0820T5E | 2 | 0805S8J0820T5E | ROYALOHM |  | 82 Ohms |  | 0805
1k | RES.(2012) 0805 1K Ohms 1% 1/8W-S 100PPM | R7, R8, R16, R18, R20 | RES 0805 YAGEO C2012X60N | RES 0805 1k Ohms 0805S8F1001TDE | 5 | 0805S8F1001TDE | ROYALOHM |  | 1k Ohms |  | 0805
3.3k | RES.(2012) 0805 3.3K Ohms 1% 1/8W-S 100PPM | R9 | RES 0805 YAGEO C2012X60N | RES 0805 3.3k Ohms 0805S8F3301TDE | 1 | 0805S8F3301TDE | ROYALOHM |  | 3.3k Ohms |  | 0805
75k | RES.(2012) 0805 75K Ohms 1% 1/8W-S 100PPM | R10, R11 | RES 0805 YAGEO C2012X60N | RES 0805 75 kOhms 0805S8F7502T5E | 2 | 0805S8F7502T5E | ROYALOHM |  | 75 kOhms |  | 0805
330k | RES.(1608) 0603 330K Ohms 1% 1/10W-S 100PPM | R12 | RES 0603 ROYALOHM | RES 0603 330k 0603SAF3303T5E | 1 |  | ROYALOHM | 0603SAF3303T5E | 330 kOhms |  | 0603 (1608 Metric)
10R | RES.(2012) 0805 10 Ohms 5% 1/8W-S 400PPM | R13, R19, R21 | RES 0805 YAGEO C2012X60N | RES 0805 10 Ohms 0805S8J0100T5E | 3 | 0805S8J0100T5E | ROYALOHM |  | 10 Ohms |  | 0805
15k | RES.(2012) 0805 15K Ohms 0.5% 1/8W 25PPM | R14, R15 | RES 0805 YAGEO C2012X60N | RES 0805 15 kOhms TC0525D1502T5G | 2 | TC0525D1502T5G | ROYALOHM |  | 15 kOhms |  | 0805
0.005R | RES.(3216) 1206 5m Ohms 1% 1/4W 100PPM AEC-Q200 SM | R17 | RES 1206 YAGEO | RES 1206 5 mOhms PE1206FRF070R005L | 1 | PE1206FRF070R005L | YAGEO |  | 5 mOhms |  | 0805
L78L33ABUTR | Linear Voltage Regulator IC Positive Fixed 1 Output 100mA SOT-89-3 | U1 | LDO L78L33ABUTR SOT89 | LDO L78L33ABUTR | 1 |  | STMicroelectronics | L78L33ABUTR
IR2103STRPBF | Half-Bridge Gate Driver IC Inverting, Non-Inverting 8-SOIC | U2, U3 | IR2103STRPBF Half Bridge Mosfet Driver | IR2103STRPBF Half Bridge MOSFET Driver | 2 |  | Infineon Technologies | IR2103STRPBF |  |  | 8-SOIC
MCP6001T-I | Standard (General Purpose) Amplifier 1 Circuit Rail-to-Rail SOT-23-5 | U4, U5, U6 | MCP6001T-I/OT OPAMP SOT-23-5 | MCP6001T-I/OT OP-AMP 1 CH LOW POWER | 3 |  | Microchip Technology | MCP6001T-I/OT |  |  | SOT-23-5

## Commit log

2026-06-26 Auto-Door-Control-Hardware-Design
    Altium Designer proje dosyaları, şematik sayfalar, PCB tasarımı, BOM dosyası ve README görselleri repoya eklendi.
    [Bill of Materials-Chicken_Coop_Door_Main_Board_V3.xlsx, Chicken_Coop_Door_Main_Board_V3.PcbDoc, Chicken_Coop_Door_Main_Board_V3.PrjPcb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]
2026-07-10 Update
    Added motor control board
    [Chicken_Coop_Door_Motor_Control_Board.PcbDoc, Chicken_Coop_Door_Motor_Control_Board.PrjPcb, Motor Control.SchDoc]
2026-07-20 Revision
    Motor control board revision
    [Bill of Materials-Chicken_Coop_Door_Motor_Control_Board_V2.xlsx, Chicken_Coop_Door_Motor_Control_Board.PcbDoc, Chicken_Coop_Door_Motor_Control_Board_V2.PcbDoc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]
2026-07-21 Revision
    Main control card is revision
    [Bill of Materials-Chicken_Coop_Door_Main_Board_V3.xlsx, Chicken_Coop_Door_Main_Board_V3.PcbDoc, External_Hardware.SchDoc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]
